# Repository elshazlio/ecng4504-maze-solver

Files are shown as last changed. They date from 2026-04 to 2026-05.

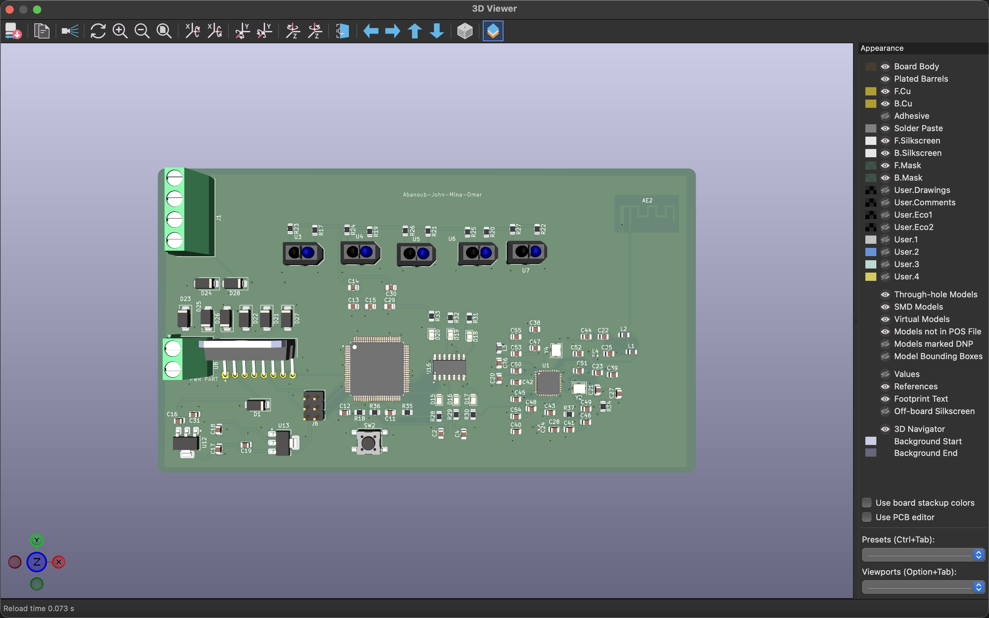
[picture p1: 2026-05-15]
Team 5 Embedded Phase 2 Submission/Screenshoots/Screenshot 2026-05-15 at 12.17.44 AM.png

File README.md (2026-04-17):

# ECNG 4504 — Autonomous maze-learning & maze-solving robot

**American University in Cairo · School of Sciences and Engineering**  
**ECNG 4504 — Embedded Systems for Wireless Communications · Spring 2026**

---

## Abstract

This project is an **autonomous line-following robot** that **learns** an unknown maze in a training pass and later **executes a shortened turn sequence** to reach the goal efficiently. A **PC host** connects over **Bluetooth** (BLE with HM-10, or **Bluetooth Classic SPP** with a ZS-040 / HC-05) to issue commands, stream status, and visualize behavior. On-robot software is a single Arduino sketch (`working_code.ino`) built around **discrete line following** (no PID), **left-hand-rule** decisions at intersections, **in-place path simplification**, and **EEPROM** persistence of the optimized path.

---

## How we approached the project

We treated the work as a loop of **measure → interpret → act → log**, repeated until the vehicle behaved reliably on real tape and real junction geometry.

1. **Hardware and sensing**  
   We brought up **five reflective sensors** (left-to-right array), **differential drive** via motor drivers, and **wireless UART on `Serial1`** (HM-10 BLE or ZS-040 / HC-05 classic) so the laptop could see the same telemetry as USB debug.

2. **Baseline motion**  
   Before worrying about mapping, we stabilized **line following** using **fixed PWM steps** and simple rules from the sensor pattern (centered forward, soft correct near center, stronger correct when the line moves under an outer sensor). This deliberately avoids PID tuning loops in favor of predictable, repeatable motion on our course.

3. **Seeing intersections**  
   Real junctions rarely match ideal drawings: wide tape, gaps, and noise meant “all black” or “wide center” could mean different things. We added **timing and lockouts** (`NODE_LOCKOUT_MS`) so the robot did not re-trigger the same junction, and **short probe moves** with **burst sampling** across the array to classify **left / straight / right** exits when possible.

4. **Training as a path string**  
   During **training**, at each real decision node the robot applies the **left-hand rule**: prefer **L**, then **S**, then **R**. The sequence of taken turns is appended to a **raw path** (`L`, `S`, `R`, or `B` for dead-end / U-turn). **Dead ends** are detected when the line is lost for long enough and recovered with a **U-turn** and a recorded **`B`**.

5. **When geometry is ambiguous**  
   For **multi-exit** junctions, recording is **deferred** briefly: after the turn, the firmware **accumulates “witness”** from the outer sensors and **scores candidate exit masks** so the stored junction record matches what the robot actually saw after committing to a turn.

6. **Optimizing the remembered path**  
   After training, the firmware **folds** the raw path: any **middle `B`** (dead-end) with neighbors is combined using **turn angles** (90° increments) so backtracking detours collapse into a single equivalent turn. That yields the **optimal path** string used in solve mode.

7. **Solve mode**  
   In **solving**, the robot walks the **optimized** sequence: at each true decision node it executes the next character of `optimalPath`. If sensor classification and the stored path disagree, it logs a **mismatch** and falls back to the left-hand choice so the run degrades safely.

8. **Host software**  
   We built a **FastAPI** dashboard with **WebSockets** (`Bluetooth stuff/maze_dashboard/`) — **Bleak** for BLE, or **pyserial** to a paired **Bluetooth SPP** serial port on macOS — plus a small **Bun** log viewer (`Bluetooth stuff/log-viewer/`) to command `TRAIN` / `START`, watch logs, and debug link issues.

**Diagrams in this repo:** high-level software structure is in [`system_architecture.png`](system_architecture.png); the PCB is exported as [`PCB Schematic.png`](PCB Schematic.png). Team and roles are in [`team.md`](team.md).

---

## Firmware: theory and implementation

The firmware implements a **maze-learning** pipeline that is **graph-free** on the MCU: the map is a **string of turns**, not an explicit adjacency list. That matches the course emphasis on embedded constraints and clear state machines.

### Line following without PID

Line tracking uses **rule-based steering** (`followLineNoPID`): the center sensor defines “on track,” left/right pairs request **differential spins** at tuned speeds (`BASE_SPEED`, `TURN_SPEED`, `ALIGN_SPEED`, etc.). There is **no PID controller**—the design trades fine continuous control for **bounded behavior** that is easier to reason about on inconsistent surfaces. After turns, **`alignToCenterStrict`** recenters on a **center-only** pattern before moving forward.

### Junction detection and training probes

A **node candidate** is inferred from reflective patterns (`nodeCandidateNow`): e.g. **all sensors on line** (wide intersection) or **outer sensors with inner body**. After a lockout window, the robot stops and runs **`inspectAndHandleNodeTraining`**: short forward motion **samples bursts** of left/right/straight visibility to set **exit masks** (bits for L, S, R). The **left-hand rule** (`selectTurn`) chooses the physical turn. **Finish** is a sustained **all-black** region confirmed as the end box (`confirmEndBox`).

### Recording and deferred resolution

For junctions with **multiple** plausible exits, the firmware may **defer** committing the recorded mask (`finalizePendingTrainingRecord`, `RECORD_RESOLVE_MS`) so post-turn sensor **witnesses** improve which mask is stored with the segment time. **Single-exit** corridors force a turn without the same ambiguity.

### Path optimization (dead-end folding)

The **raw** training path includes detours. **`buildOptimalPath`** repeatedly replaces triples where the **middle turn is `B`** by summing **turn angles** (L = 270°, S = 0°, R = 90°, B = 180°) and mapping the result back to a single letter. This removes redundant **out-and-back** structure while preserving net heading.

### Solving

**Solve** mode (`inspectAndHandleNodeSolving`) indexes **`optimalPath`** with `solveStepIndex`. Only at **true** decision nodes (multiple exits, or zero exits) does it consume the next stored turn; **forced** corridors follow the obvious exit. EEPROM (`EepromMazeData`) can persist raw and optimized paths across power cycles (`LOAD`, `CLEAR`, auto-load on boot).

### Commands and telemetry

**USB and wireless UART** share the same command set (`TRAIN`, `START`/`SOLVE`, `STATUS`, `DUMP`, `LOAD`, `CLEAR`, `STOP`). Status lines (`STATE`, `STAGE`, paths, node logs) go to both streams for the dashboard and debugging.

---

## Repository contents

| Deliverable | Location |
|---|---|
| MCU firmware (final) | [`working_code.ino`](working_code.ino) |
| Backend (FastAPI, BLE, WebSockets) | [`Bluetooth stuff/maze_dashboard/`](Bluetooth%20stuff/maze_dashboard/) |
| Web UI (log viewer) | [`Bluetooth stuff/log-viewer/`](Bluetooth%20stuff/log-viewer/) |
| BLE helper scripts | [`Bluetooth stuff/ble_log_receiver.py`](Bluetooth%20stuff/ble_log_receiver.py), [`Bluetooth stuff/ble_scan.py`](Bluetooth%20stuff/ble_scan.py), [`Bluetooth stuff/requirements.txt`](Bluetooth%20stuff/requirements.txt) |
| Bill of materials | [`component_list(1).xlsx`](component_list%281%29.xlsx) |
| Software architecture diagram | [`system_architecture.png`](system_architecture.png) |
| PCB schematic (image export) | [`PCB Schematic.png`](PCB%20Schematic.png) (also under [`KiCAD Stuff/`](KiCAD%20Stuff/)) |
| KiCAD project (native) | [`KiCAD Stuff/`](KiCAD%20Stuff/) — `Embedded Project.kicad_pro`, `.kicad_sch`, `.kicad_pcb`, `.kicad_prl` |
| Team | [`team.md`](team.md) |
| 3D / mechanical design | [`3d design/`](3d%20design/) (Fusion 360 `.f3z`) |
| Local dev (env + both servers) | [`DEV-SERVERS.md`](DEV-SERVERS.md) |

**KiCAD:** open **`KiCAD Stuff/Embedded Project.kicad_pro`** in **KiCad**. Local editor folders (`.history/`, `*-backups/`, lock files) are gitignored.

---

## Running the PC applications

The host uses the **same UART protocol** as USB; the **radio path** is either **Bluetooth Classic SPP** (ZS-040 / HC-05) or **BLE** (HM-10 / Nordic UART). Full copy-paste flows (both apps, stop commands, ports) are in **[`DEV-SERVERS.md`](DEV-SERVERS.md)**.

- **Classic SPP (`ZS-040 / HC-05`):** pair in macOS, then set `MAZE_BT_SERIAL` to the paired `/dev/cu.*` device (and `MAZE_BT_BAUD`, usually `9600`). Applies to **both** the maze dashboard and the log viewer.
- **BLE:** leave `MAZE_BT_SERIAL` unset. Point the **dashboard** at the robot with `MAZE_BLE_ADDR` (fixed address, skips scanning) or `MAZE_BLE_NAME` (scan by advertised name). The **log viewer** does **not** use `MAZE_BLE_ADDR`; it still expects `MAZE_BT_SERIAL` for Classic SPP.

**Maze dashboard (first-time venv)**

```bash
cd "Bluetooth stuff/maze_dashboard"
python3 -m venv .venv && source .venv/bin/activate && pip install -r requirements.txt
uvicorn app:app --reload --host 127.0.0.1 --port 8765
```

**ZS-040 / HC-05 on macOS (Bluetooth Classic SPP)** — pair the module in **System Settings → Bluetooth**, then pick the outgoing serial device (names vary; often under `/dev/cu.*`):

```bash
ls /dev/cu.*
export MAZE_BT_SERIAL=/dev/cu.YourModule-DevB
export MAZE_BT_BAUD=9600
cd "Bluetooth stuff/maze_dashboard"
source .venv/bin/activate
uvicorn app:app --reload --host 127.0.0.1 --port 8765
```

After a successful connection, you can use `export MAZE_BT_SERIAL=last` to reuse `bt_serial_last.json` beside `app.py`.

**Maze dashboard (BLE by address — example)**

Use when the robot is on the BLE path and you already know its address:

```bash
unset MAZE_BT_SERIAL
unset MAZE_BT_BAUD
export MAZE_BLE_ADDR=78:04:73:16:19:C7
cd "Bluetooth stuff/maze_dashboard"
source .venv/bin/activate
uvicorn app:app --reload --host 127.0.0.1 --port 8765
```

For scan-based BLE instead of a fixed address, omit `MAZE_BLE_ADDR` and optionally set `MAZE_BLE_NAME`. See `Bluetooth stuff/maze_dashboard/app.py` (module docstring) and `ble_discover.py` for UUID discovery.

**Path preview (SVG map):** The dashboard builds a **turtle-geometry** polyline from path strings and from **training/solve** turn lines in the log (`FORCED_TURN`, `SOLVE_FORCED_TURN`, `SOLVE_NODE`, etc.). The preview appends **one grid segment after the last logged turn** so the **final leg** and **forced** corridor exits show the same corners you see on the track; that step is **visualization-only** and does not change what the robot records or executes. Optional **local-only** regression tests for the map (not published on GitHub) may exist under `Bluetooth stuff/maze_dashboard/`; if you have them, run with `python -m unittest` in that folder using the project venv.

**Log viewer** (see `Bluetooth stuff/log-viewer/package.json` for scripts). This path uses `ble_log_receiver.py` and **Classic SPP only** — set `MAZE_BT_SERIAL` in the same shell.

```bash
cd "Bluetooth stuff/log-viewer"
bun install
export MAZE_BT_SERIAL=/dev/cu.YourModule-DevB
bun run serve
```

---

*Course project repository: **ecng4504-maze-solver_team_5** — maze learning and solving per the ECNG 4504 charter.*

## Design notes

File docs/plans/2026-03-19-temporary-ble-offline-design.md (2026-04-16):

# Temporary BLE Offline Mode Design

## Goal

Keep the car firmware, Bluetooth helper scripts, and local log viewer aligned with the current hardware reality while the HM-10 module is unavailable.

## Proposed Approach

Use a compile-time BLE availability flag in `working_code.ino` so the sketch keeps USB serial telemetry but does not initialize or write to `Serial1` during the outage. Keep the BLE-related code structure intact so the replacement module can be re-enabled by changing one flag instead of reconstructing earlier integration work.

Update the Bluetooth scripts and log viewer to present a clear temporary-outage state instead of trying to scan or connect to HM-10. This keeps the tooling honest and prevents wasted debugging effort on a module that is currently dead.

## Scope

- Firmware: disable HM-10 initialization and mirrored BLE telemetry
- Docs: mark the HM-10 entry and BLE workflow as temporarily unavailable
- Tools: make BLE scripts/viewer report outage status explicitly

## Non-Goals

- Permanent removal of BLE support
- Replacing Bluetooth with a different wireless transport
- Solving the current junction/phantom-turn regression in this same change

## Validation

- Host-side firmware tests still compile and pass
- BLE scripts show a temporary outage message without trying to connect
- Viewer status text reflects the offline state

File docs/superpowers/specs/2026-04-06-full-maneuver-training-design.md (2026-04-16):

# Full Maneuver Training Design

## Goal
Make training, logs, EEPROM data, and solve playback all describe the same thing: the exact maneuver stream the robot physically executed, including forced turns, decision-node turns, straight-through traversals, and dead-end U-turns.

## Problem Summary
The current firmware stores a reduced path model that intentionally records only real decision nodes and dead ends. That design no longer matches the required behavior. It also makes debugging harder because the operator sees one sequence while the firmware stores another. On top of that, the current node-selection flow can misclassify some non-left nodes as `L` because sensing and turn selection are coupled through a left-first policy.

## Recommended Architecture
Replace the current junction-only raw path model with a maneuver-stream model.

Each stored step represents one executed maneuver, not one inferred junction. A step must contain:
- maneuver turn: `L`, `S`, `R`, or `B`
- event kind: forced, decision, or dead-end
- sensed exits mask for the triggering location when applicable
- segment time for the travel leading into that step

This creates one canonical sequence that can be:
- logged directly during training
- saved to EEPROM without losing forced maneuvers
- inspected later without reconstructing hidden steps
- replayed during solve with event-aware logic

## Component Changes
### Training recorder
Training should append a step whenever the robot commits to an executed maneuver.

That includes:
- forced single-exit turns
- decision-node turns after probe resolution
- zero-exit recovery only when the firmware has positively classified a dead end
- straight-through traversals when the robot intentionally continues straight

The node probe must stop using "first available left/straight/right" as the stored-truth generator. Instead, sensing should determine what exits exist, and a separate decision step should determine which maneuver is executed and recorded.

### Data model
The current arrays store only turn char, exits mask, and segment time. They need one additional event-kind field so the firmware can distinguish:
- a forced `L` from a decision-node `L`
- a straight forced corridor continuation from a decision-node `S`
- a true dead-end `B` from a temporary zero-exit probe failure

The event kind must be persisted alongside the turn sequence in RAM and EEPROM.

### Solve playback
Solve should no longer assume that only multi-choice nodes consume stored path entries. Instead, it should replay the same maneuver stream model that training recorded.

This means solve must:
- inspect the current sensed exits
- verify the next stored maneuver is still plausible
- execute the stored maneuver with the same motor routine used in training
- surface a clear mismatch log if the maze geometry no longer matches the stored step

### Path reduction
The current optimizer reduces `xBx` patterns in a junction-only path. That logic is too weak once forced maneuvers are included.

Optimization should therefore become event-aware:
- only consider simplification across dead-end events
- never collapse across forced moves that are part of the physically required route
- preserve a raw full-stream path exactly, even if an additional derived optimized path is built later

The raw full-stream sequence is the source of truth. Any optimized sequence is secondary and must be derivable without destroying the original record.

## Data Flow
1. Training follows the line.
2. When the robot reaches a location that requires action, sensing classifies the situation.
3. The firmware decides the executed maneuver.
4. The firmware performs that maneuver.
5. The firmware records one maneuver-stream step with event kind, turn, exits, and segment time.
6. EEPROM persistence saves that full stream.
7. Solve loads the same stream and replays it step by step.

## Error Handling
- If sensing sees no exits during a normal probe, the firmware must distinguish between a confirmed dead end and a transient probe miss before recording `B`.
- If solve reaches a step whose stored maneuver is impossible for the currently sensed exits, the firmware should log a path mismatch with both the stored step and live exits.
- If EEPROM data is from the older junction-only format, the firmware should reject it or version it clearly rather than silently interpreting it as full-stream data.

## Testing Strategy
Because this change alters the storage model, behavior must be locked down with regression coverage before production edits:
- add tests for maneuver recording so forced, decision, straight, and dead-end events all append correctly
- add tests proving false-left contamination does not rewrite intended straight decisions
- add tests for EEPROM round-trip of the extended step model
- add tests for solve playback consuming forced and decision events from the same stored stream
- add tests for any optimizer so it preserves the raw stream and only reduces allowed dead-end patterns

## Success Criteria
The design is successful when:
- the training log can represent the exact physical maneuver sequence the operator observed
- the saved raw path preserves forced and decision steps without collapsing them into a junction-only abstraction
- solve playback consumes that same path model consistently
- a run that physically contains straight-through `SR` decisions can no longer be recorded as all-left unless the sensors actually reported that geometry

## Scope Boundaries
This change is focused on path semantics and recording/playback correctness. It does not require a new UI, a new communications protocol, or a large unrelated refactor of line-following motor control unless tests prove one of those layers is the root cause of a remaining misclassification.

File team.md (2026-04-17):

# Team 5: ECNG 4504

**Course:** Embedded Systems for Wireless Communications · Spring 2026  
**Institution:** American University in Cairo · School of Sciences and Engineering

## Members

| Name | ID | Email |
| --- | --- | --- |
| Abanoub Emad Said Kamel | 900201630 | [abanoubemad@aucegypt.edu](mailto:abanoubemad@aucegypt.edu) |
| John Kamal | 900212208 | [johnk.kamal@aucegypt.edu](mailto:johnk.kamal@aucegypt.edu) |
| Mina Yasser Gerges | 900214039 | [Minayasser@aucegypt.edu](mailto:Minayasser@aucegypt.edu) |
| Omar ElShazli | 900201477 | [Elshazlio@aucegypt.edu](mailto:Elshazlio@aucegypt.edu) |

---

## Contributions (aligned with this repository)

### Mina Yasser Gerges

Led the **on-robot firmware** in `working_code.ino`: maze **training** and **solving** behavior (map build, optimal path execution, left-hand-rule navigation), sensor and motion tuning, and calibration for reliable runs. Integrated **BLE (HM-10)** with the main control flow and supported **robot-side** wireless testing so the PC tools could drive and monitor the vehicle end-to-end. Also led **hardware assembly** and **reassembly** after numerous failures during bring-up, keeping the mechanical and electrical stack usable for continued software iteration.

### Abanoub Emad Said Kamel

Led **hardware**: component selection and the **bill of materials** (`component_list(1).xlsx`), wiring, and motor/sensor interfacing. Prepared the **schematic** and carried the design through **PCB layout and routing**—trace planning, **footprint placement**, **ground and power planes**, clearance and **design-rule** checks for a board that could be fabricated and assembled reliably—with the schematic exported as `**PCB Schematic.png`** in this repo.

Led **3D mechanical design in Autodesk Fusion** (**Fusion 360**): chassis and related parts, **parametric modeling**, and **assembly** so motors, sensors, and the PCB stack fit the platform; sources are in `**3d design/`** (Fusion archive per `[README.md](README.md)`).

### John Kamal & Omar ElShazli

Led **host-side software** that talks to the robot over **wireless UART** (same framing as USB), with a **dual transport** so the laptop stack could follow the hardware path from **HM-10 (BLE)** to **ZS-040 (Bluetooth Classic serial / SPP)** — often on an **HC-05**-class breakout — without rewriting the application. **Transport selection** is by environment: leave `**MAZE_BT_SERIAL` unset** for **Bleak + HM-10**, or set it to a `**/dev/cu.*`** device for **pyserial + ZS-040**.

**Maze dashboard (`Bluetooth stuff/maze_dashboard/`):**

- **FastAPI** backend with **WebSockets** so the browser gets **live telemetry** (logs, phase, paths, pause state) as the robot prints lines.
- **HM-10 path:** **Bleak** scans and connects to the advertised module, discovers **Nordic UART Service** or **HM-10-style FFE1** characteristics, and bridges notify/write to the same command and log pipeline the firmware already uses on `Serial1`.
- **ZS-040 / HC-05 path:** when the vehicle moved to a **paired Bluetooth Classic** module, the host opens a **serial port** (`pyserial`) on macOS `**/dev/cu.*`** instead of BLE — driven by `**MAZE_BT_SERIAL**` and `**MAZE_BT_BAUD**`, with optional reuse of the last good port via `**bt_serial_last.json**` so development sessions did not require rediscovering the device name every time.
- **Browser UI:** command buttons (`TRAIN`, `START`, etc.), scrollable log with tagged lines (paths, nodes, turns), and an **SVG path preview** built from firmware path strings and solve/training turn lines (turtle geometry, including visualization fixes for forced vs intersection legs).
- **Run archive** (saved sessions) and supporting helpers such as `**ble_discover.py`** to capture UUIDs and a stable BLE address for faster reconnects.

**Log viewer (`Bluetooth stuff/log-viewer/`) and streaming:**

- Bun-based **web** UI served alongside small Node/Bun glue, with `**ble_log_receiver.py`** sharing the same `**MAZE_BT_SERIAL**` / `**MAZE_BT_BAUD**` convention as the dashboard so logs could be tailed and debugged outside the full stack when needed.
- Supporting scripts `**ble_discover.py**`, `**ble_scan.py**`, and `**ble_log_receiver.py**`, plus **end-to-end testing** of dropouts, partial lines, and reconnect behavior against the real link.

**HM-10 → ZS-040 shift and challenges:**

- **Different stack on the PC:** BLE used **GATT notify/write** and scan/pair semantics; classic Bluetooth used **macOS pairing in System Settings** and **serial port enumeration**, which changed how we diagnosed “no data” (wrong `/dev/cu.*` outlet vs wrong baud vs module not connected as SPP).
- **Operational friction:** finding the correct **callout serial device**, matching **baud** to firmware (`MAZE_BT_BAUD`), and avoiding stale **BLE** assumptions when the robot no longer exposed a GATT UART service.
- **Reliability:** reconnection after sleep or unplug, **line-boundary** issues in streaming text, and keeping **one mental model** (command + log stream) across two transports so `**working_code.ino`** did not need parallel host protocols.

---

*Repository deliverables (firmware, PC apps, BOM, schematic image, mechanical CAD) are listed in `[README.md](README.md)`.*

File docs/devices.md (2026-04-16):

# Phased Implementation Plan (Arduino Mega + HM-10 + 5-Eye IR + L298N + 4 DC Motors)

## 1) Project Context and Constraints

- **MCU:** Arduino Mega 2560
- **Wireless:** HM-10 BLE 4.0 module (UART to Mega) - temporarily offline after suspected 5V overvoltage damage
- **Sensing:** 5-eye IR line sensor array
- **Actuation:** L298N motor driver + 4 yellow DC motors
- **PC side:** Python 3 already installed
- **Course constraints:** MCU code in C/C++, BLE link to PC app, autonomous training + solving behavior
- **Current temporary status:** BLE is disabled in the sketch and helper tools until the replacement HM-10 arrives; use USB serial telemetry for tuning in the meantime

---

## 2) Extra Software Prerequisites (Beyond Python 3)

## Required

1. **Arduino IDE 2.x** (or `arduino-cli`)
  - Install AVR core ("Arduino AVR Boards")
  - Needed to build/upload firmware to Arduino Mega
2. **USB-to-Serial driver** (only if your Mega clone needs it)
  - Typical chipsets: CH340 or CP210x
  - Verify serial port appears on macOS after connection
3. **Python packages**
  - `pyserial` (serial debugging and optional UART tooling)
  - `bleak` (BLE communication with HM-10 from laptop, temporarily unused until replacement hardware arrives)
  - `matplotlib` (path/maze visualization)
  - `networkx` (graph and shortest-path operations)
  - `pytest` (automated tests for planner/protocol)
4. **Git + GitHub account**
  - Required for collaboration and deliverables
5. **KiCad**
  - Required for schematics/PCB deliverables in later phase

## Recommended

1. **BLE debugging app** (LightBlue or nRF Connect)
  - Useful again after the replacement HM-10 is installed; currently blocked by the temporary BLE outage
2. **Serial monitor tool** (Arduino Serial Monitor or CoolTerm)
  - Faster telemetry debugging during motor/sensor tuning
3. **Diagram tool** (draw.io/Figma/Luidchart)
  - For architecture, FSM, and reporting diagrams

## Python package install command

```bash
python3 -m pip install pyserial bleak matplotlib networkx pytest
```

---

## 3) Firmware and PC Module Breakdown

## Firmware (Arduino Mega)

- `board_init`: pin mapping, timers, UART init, startup checks
- `motor_driver`: PWM + direction control for left/right motor groups
- `sensor_reader`: raw IR sampling and calibration normalization
- `line_controller`: line position error and steering correction logic
- `intersection_detector`: detect node/intersection events
- `maze_mapper`: store discovered nodes/edges during training run
- `path_planner`: shortest path generation from mapped graph
- `solver_executor`: execute computed path physically on track
- `ble_link`: UART protocol handling to/from HM-10 (temporarily disabled in firmware during the outage)
- `robot_fsm`: high-level states (Idle, Train, Plan, Solve, Done, Error)
- `telemetry_logger`: compact status/event output for debug and PC app

## PC (Python)

- `ble_client`: discovery/connect/read/write/reconnect logic (temporarily unavailable until replacement hardware arrives)
- `command_console`: send commands (`train`, `solve`, `stop`, `reset`)
- `status_monitor`: live stage/status/error output
- `maze_visualizer`: display mapped maze and final chosen route
- `session_logger`: save run metadata and final path per trial
- `protocol_codec`: encode/decode command and telemetry packets

---

## Known Device Addresses

| Device | Address (macOS UUID) | Notes |
|---|---|---|
| HM-10 (HMSoft) | `07B13CAC-B95B-5DB8-18DF-C4C18A5AECE1` | Temporarily offline after suspected 5V overvoltage damage; keep address for the replacement bring-up |

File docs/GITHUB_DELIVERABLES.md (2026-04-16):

# GitHub contents vs. course charter deliverables

This file ties the **[project charter](project_description.md)** (“Github repository link that has the following content…”) to **folders and files in this repository**. Use it when preparing Phase 0 / 1 / 2 zip submissions so the link matches what instructors expect.

## Phase 0 — Initial demonstration

Charter asks for a **GitHub repository link** containing:

| Deliverable | In this repo |
|---|---|
| **(a) MCU code** | Arduino sketches at repository root (e.g. `working_code.ino`, `mina_final_code.ino`, `probably_final_code.ino`). Supplementary C++ tests under `tests/` where applicable. |
| **(b) Initial software architecture and hardware schematics (KiCAD)** | `Architecture Diagram Only.docx`, `PCB Schematic.png`, `Maze.png`, `component_list(1).xlsx`, materials under `3d design/`, and any further diagrams under `docs/`. |

Also required in the **zip** (not necessarily all in Git, but often mirrored): Excel components list, demo video, contribution write-up, `team.txt`, etc.—see charter.

**Note:** Phase 0 states wireless communication is **not** required; BLE/Python tooling may still be present for team use.

## Phase 1 — Final demonstration

| Deliverable | In this repo |
|---|---|
| **(a) MCU code** | Same as Phase 0; keep the branch/tag used for the demo identifiable (commit message or release). |
| **(b) Python script code** | `Bluetooth stuff/maze_dashboard/` (main FastAPI application), plus `Bluetooth stuff/log-viewer/` if used as part of the laptop workflow. |
| **(c) Updated software architecture and hardware schematics (KiCAD)** | Updated diagrams and schematics in `docs/`, `Architecture Diagram Only.docx`, `PCB Schematic.png`, `3d design/`, etc., as revised for Phase 1. |

Document **architecture or wiring changes** in `docs/` (and/or AgDRs in `docs/agdr/`) so “any change… shall be documented along with the reason” is satisfied.

## Phase 2 — Product / PCB

| Deliverable | In this repo |
|---|---|
| **KiCAD project files, Gerbers, BOM, FSM, 3D screenshots, manufacturer screenshot** | Typically under `3d design/`, `docs/`, and any `*.kicad_*` / Gerber folders you add. Expand this section as files are committed. |

## Maintenance

When you add KiCAD projects, Gerbers, or new Python modules, update this file and the root **README** table so reviewers can find them in one pass.

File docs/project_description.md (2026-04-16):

The American University in Cairo - School of Sciences and Engineering
Department of Electronics and Communication
ECNG 4504 - Embedded Systems for Wireless Communications
Spring 2026

# ECNG 4504 Project Charter

## Project Description

This project aims to provide a hands-on experience in embedded systems through the design and implementation of an autonomous
robotic vehicle capable of learning and solving a maze with minimal user intervention. The maze consists of interconnected paths
marked on the floor, which the robot initially explores during a training phase in order to build an internal representation of the maze
structure. Based on the acquired data, the robot is then required to compute and execute the optimal path to solve the maze.
Communication between the robotic vehicle and a personal computer (PC) is established via a Bluetooth wireless link, BLE, specifically.
A Python-based application running on the PC interacts with the robot by issuing high-level commands, such as initiating the training
phase and triggering the maze-solving phase. Upon completion of the solving process, the robot transmits the final computed path back
to the PC for visualization, logging, or further analysis and it shall output some indication in real-time aws to what stage the robot is at
during solving phase.

The robotic vehicle operates autonomously while navigating the maze, ensuring accurate path detection, correct decision-making at
intersections, and reliable execution of turns without deviating from the designated track.

1. The robot’s maximum size is40 cm x 40 cm.
2. The robot’s maximum weight is2 Kg

## Robot Vehicle Constraints

The following constraints have to be met; otherwise, it will result in a deduction of 5% of the Project’s Total grade for each violation:

```
.
```
3. Using ready-made robots designed for line following isprohibited(only ready-made chassis, modules, breakout boards, etc... are
    permitted).
4. It has to be abattery-poweredSystem.
5. OnlyC/C++ programming languagesare allowed for MCU code.

## Instructions & System Constraints

Each team can consist of exactly 4 members. No more and no less. The tracks will follow these specifications:

1. The track line color is black on a white background.
2. The track line width is3 cm.
3. Only90-degreeturns are present as types of turns.
4. Track lines will contain intersections between 2 lines.

One (1) PDF representing the track for experimentation (Maze_1.pdf). The size of the printable PDF is 200cm x 200cm. Different
undisclosed tracks will be used for the evaluation in both Phase 0 and 1 of the projec.will be provided then.

During the evaluation of the project, each Team is given three (3) trials for both training and testing, and a trial is considered successful
if it completes both training and testing smoothly.
It is considered to have failed if any of these conditions occurs:

1. 360 rotations during training or testing,
2. leaving the line during training or testing,
3. manually rectified/pushed during training or testing,
4. exceeding 5 minutes during training,
5. not reaching the target point during testing
Reprogramming after/before each trial is allowed for tuning faster runs during testing. Any failed trial has to be documented with an
explanation of why it failed. However, failure to do a live-demo during dem or taking more than 3 trials will result inpenalities.

### 4.

## Phase 0 - Inital Demonstration

In this phase, you shall perform research to decide which components will be used. System architecture and coding style shall also be
agreed on. The platform (software tools, IDE, etc... ) through which all team members will work has to be unified among the members
of the same team. The robotic vehicle must successfully traverse through the maze once for training and traverse it once more for
solving it. The wireless communication is not required in this phase. A to-be-announced day will be scheduled for a live demo where
each team will be given three (3) trials.
Evaluation on this phase shall not have a great weight on the performance of the car, but rather on other aspects like
code sophistication, understanding of the code, innovative approaches, documented trials and errors, etc... ,
meaning that writing a simple, basic code that works does not guarantee getting a full mark in this phase.
Phase Deliverables - One Zip file named after Team number with the following content inside it:

1. An Excel sheet containing a list of components.
2. Pre-prepared demo video.
3. Contribution of each team member.
    Githubrepository link that has the following content:
       (a)MCU code.
(b)Initial software architecture and hardware schematics diagrams (hardware connections has to be done initially onKiCAD).

```
Phase Deadline:
```
5. Text file containing team details (names, IDs, emails, and team number).
6. Group Teammate Eval Form (online per individual)
All of the above phase delivered diagrams have to be designed properly using one of the computer-aided design (CAD) software
tools, submission of the design as just a hand-drawing is not acceptable and will be penalized for that.
23:59 Tuesday, March 10th, 2025 (week 6) - discussion and demo will be held the next day during class time.

1. Pre-prepared demo video.
2.

## Phase 1 - Final Demonstration

In this phase, you will be given a new track (i.e., you will see this track for the first time on the discussion day), on which you shall
run your robotic vehicle successfully with an added wireless communication link to the PC to implement your choice of control and
status reporting. The python script app running on your laptop/PC has to be proven to work with the robotic vehicle. Any change
in software architecture, hardware connections, etc... shall be documented along with the reason for such change. A to-be-announced
day will be scheduled for a live demo where each team will be given three (3) trials for the final track.
Evaluation on this phase shall have a larger weight on the implementation of the wireless feature and the performance of the car,
while other aspects like codesophistication, understandingofthecode,innovativeapproaches,documentedtrialsanderrors,etc...,
have less weight..

Phase Deliverables - One Zip file named after Team number with the following content inside it:

```
Contribution of each team member.
```
3. Githubrepository link that has the following content:
    (a)MCU code.
(b)Python script code.
(c)Updated software architecture and hardware schematics diagrams (hardware connections has to be done initially onKiCAD).

```
Phase Deadline:
```
4. Text file containing team details (names, IDs, emails, and team number).
5. Group Teammate Eval Form (online per individual)
All of the above phase delivered diagrams have to be designed properly using one of the computer-aided design (CAD) software
tools, submission of hand-drawing is not acceptable and will be penalized for that.

```
23:59 Friday, April 17th, 2025 (week 12) - discussion and demo will be held the next day during class time.
```
## Phase 2 - Designing the project as a product

In this phase, you are required to design the PCB using KiCAD for your car as if you were to sell it. The design has to mechanically fit in
your original car used in phase 1. all of the used components must be “in stock” on LCSC and they must adhere to PCB Manufacturi
ng&

### 1.

```
Assembly Capabilities of JLCPCB. Also, all of the components used from LCSC shall be SMD components not THT
```
. You are not allowed to choose any other manufacturer than JLCPCB, nor any other distributor than LCSC.(through hole)
One other extra requirement is a FSM diagram of your whole project, defining the behavior of your code.
Phase Deliverables - One Zip file named after Team number with the following content inside it:

```
Githubrepository link that has the following content:
(a)KiCAD project files.
```
Phase Deadline:

2. Contribution of each team member.
3. Gerber files of the PCB.
4. Screenshot from the PCB manufacturer website before ordering the PCB.
5. 3D view screenshot of your PCB in KiCAD.
6. Text file containing team details (names, IDs, emails, and team number).
7. FSM diagram of your whole project, defining the behavior of your code.
8. Group Teammate Eval Form (online per individual)
All of the above phase delivereddiagrams have to be designed properly using one of the computer-aided design (CAD) software
tools, submission of the design as hand-drawing is not acceptable and will be penalized for that.
23:59 Tuesday, May 12th, 2025 (week 15) - discussion will be held the next day during class time.

## Grading Rubric

Regarding any of the below project phases rubrics, Teams will be arranged from the best to the worst and are given the grade accordingly;
the same goes for the other aspects of the project. Also, given any rubric; every team membermust havecomplete understanding of
that item as grades are assigned individually per team members. Any violations oftheAUCCodeofAcademicEthics will be penalized
heavily.

1. Phase 0 - Inital Demonstration. (30%)
    a. Documentation and Code Organization (2%)
    b. Initial Software Architecture and Hardware Connection Diagrams (3%)
    c. A successful, smooth run on the given track (35%) - most of this grade is related to other aspects like code sophistication,
       amount of effort documented, and so on. A little weight is given to car performance (speed and smoothness).
2. Phase 1 - Final Demonstration. (40%)
    a. Wireless connectivity feature (15%)
    b. Documentation and Code Organization along with the hardware connection (5%)
    c. A successful, smooth run on the final demo day track (20%) - most of this grade is related to car performance (speed and
       smoothness), while other aspects are given lower weight.
3. Phase 2 - Designing the project as a product. (30%)
    a. hardware schematics (10%)
    b. PCB layout and design (10%)
    c. FSM diagram (5%)
d. BOM (bill of material) (2%)
e. 3D view of the PCB, screenshot from the manufacturer website along with the gerber files (3%)

## Bonus

A bonus that will not exceed 10% of the project’s total weighted grade is available. The bonus will be awarded to any of the following
contributions up to a maximum of the percentage in front of each item:

1. RTOS-based project (e.g. freeRTOS, Zephyr, etc... ) on the main car’s MCU. (10%)
2. Low-level driver implementation. (10%)
3. Applying one of the famous controllers (e.g., PID, etc... ) (10%)
4. 3D designing of the car body chassis (10%)

Any other extra work will be considered for a bonus at the discretion of the instructors and will be evaluated according to the complexity
of the work done, but the overall bonus will not exceed 10% of the project’s total weighted grade under any condition. Check with the
instructors before the phase deadline if you think you have any other item that qualifies for a bonus.

## Notes

1. The bonus gradedoesnot contributeto midterm and final exam grades. However, it can contribute to Class performance, quizzes,
    and assignment grades in case of getting a grade higher than the project total grade.
2. Completing one loop of the trackisnot sufficientto get the full grade; rather, consistent car performance on the track is taken
    into consideration upon grading with other aspects, as mentioned before.
3. You are free to choose any line tracker sensor of your choice, but due to some inconveniences your colleagues faced before, we
    recommend using thisLineTrackerSensor. Note that we have no association of any kind with any of the companies/stores linked
    in this document.
4. The delivered diagrams (FSMs, hardware connections, software architecture, etc... ) have to reflect what was actually imple-
    mented in phase 0/1; otherwise, a partial grade will be earned.
5. The “group team-mate eval” Google form is mandatory to fill out for each individual in the same team to ensure fairness in grading
    team members. This means that it is expected and quite normal that team members in the same team will get different grades. Any
    team member who doesn’t fill out the peer evaluation form by the deadline will be given 0.
6. You as a team are totally responsible for work distribution among you, meaning that, if a team member work distribution is less
    than the rest of the team, he/she would be penalized for that; so make sure to distribute the workload among you equally. In case
    you mentioned in the work distrubition sheet that “all of you worked together on the same thing”, then, during discussion, it’s
    assumed that all of you know everything about the project.

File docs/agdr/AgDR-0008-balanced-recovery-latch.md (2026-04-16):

---
id: AgDR-0008
timestamp: 2026-03-18T00:00:00Z
agent: cursor
model: GPT-5.4
trigger: user-prompt
status: executed
---

# Balanced Recovery Latch For Junction Turns

> In the context of a partially working `working_code.ino` Phase 0 maze follower, facing missed or late turns caused by staggered sensor triggering, crooked approach angles, and forward momentum through intersections, I decided to use a short guarded recovery latch that preserves recent committed junction intent only while the post-junction reading is uncertain and releases on a clearly centered follow reading, to improve turn reliability while accepting heuristic thresholds and possible hardware retuning.

## Context
- The sketch already records a committed intersection intent, but currently reuses it only during full all-black crossings.
- Real hardware can produce staggered or partial sensor patterns after a junction because the five sensors do not trigger simultaneously.
- The robot must continue respecting left-hand following, so a confidently seen left should not be discarded too quickly.
- A full follower/node/turn state machine would be more structured, but is larger and riskier than needed for this pass.

## Options Considered
| Option | Pros | Cons |
|---|---|---|
| Keep the current all-black-only latch and only retune timing constants | Smallest code change, easiest to compare with current behavior | Does not address messy partial post-junction readings, still likely to forget left too early |
| Use a balanced recovery latch during uncertain post-junction readings | Targets staggered sensors and momentum, preserves left-hand priority without overcommitting too long | Adds heuristic ambiguity rules and another timing window to tune |
| Use an aggressive sticky latch until a strong competing pattern appears | Most likely to catch late turns after overshoot | Higher risk of false turns and suppressing valid live corrections on noisy tracks |

## Decision
Chosen: **Use a balanced recovery latch during uncertain post-junction readings**, because it directly addresses the observed goldfish-memory behavior after junctions while still allowing clear live sensor patterns to retake control before the robot commits to a wrong branch.

## Consequences
- The robot should keep honoring a recent left or straight node intent through brief partial/noisy recovery readings after a junction.
- A clearly centered follow reading should release the latch so normal line following resumes promptly.
- Left-hand following remains preserved because new clear left evidence still outranks older non-left intent.
- The sketch stays heuristic; if hardware testing still shows inconsistent behavior, the next step should be a fuller state-machine rewrite rather than more ad-hoc latch growth.

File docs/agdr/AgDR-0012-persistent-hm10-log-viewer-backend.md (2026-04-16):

---
id: AgDR-0012
timestamp: 2026-03-19T00:00:00Z
agent: cursor
model: GPT-5.4
trigger: user-prompt
status: executed
---

# Use A Persistent HM-10 Viewer Backend

> In the context of the local HM-10 log viewer, facing misleading UI connection state, lost reconnect behavior after the car power cycles, and noisy unreadable sensor output, I decided to use a persistent server-managed BLE backend with UI-side grouped rendering to achieve accurate status and automatic recovery, accepting more backend state management than the current per-page spawn model.

## Context
- The current Bun page opens a WebSocket and immediately marks the UI as connected when the socket opens, even though BLE connection may still be in progress.
- The current server spawns a BLE reader per browser socket, so clearing logs or losing the BLE device often leaves the page needing a manual refresh to recover cleanly.
- The user wants sensor lines grouped between `Node detected` lines and expandable for easier reading.
- Browser-only BLE was already ruled out because the user wants automatic reconnect behavior.

## Options Considered
| Option | Pros | Cons |
|---|---|---|
| Persistent server-managed BLE session with broadcast events to the UI | Accurate BLE lifecycle state, automatic reconnect after power cycling, single source of truth for all tabs, keeps browser simple | Requires backend supervisor logic and event protocol instead of raw text piping |
| Keep per-page WebSocket and respawn BLE reader on each page load | Smaller change from current code, simpler server file | Connection state stays tied to page lifecycle, reconnects remain fragile, multiple tabs can compete for BLE |
| Return to browser-managed Web Bluetooth | Familiar direct browser API, no Python bridge | Cannot reliably auto-connect or auto-reconnect due to browser permission and gesture limits |

## Decision
Chosen: **Persistent server-managed BLE session with broadcast events to the UI**, because the core problems are lifecycle and truth-of-state problems that are best solved once in the backend instead of asking each browser tab to infer BLE status from a short-lived subprocess.

## Consequences
- The Bun server will maintain one long-lived BLE supervisor process and stream structured status/log events to the browser.
- The page will show `searching`, `connected`, and `reconnecting` based on backend events rather than WebSocket state alone.
- Sensor lines will be grouped client-side under each `Node detected` anchor for readability.
- The implementation is slightly more complex than raw stdout piping and needs tests around grouping/state behavior.

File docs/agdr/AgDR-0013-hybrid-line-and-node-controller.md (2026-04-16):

---
id: AgDR-0013
timestamp: 2026-03-19T03:59:41Z
agent: cursor
model: GPT-5.4
trigger: user-prompt
status: executed
---

# Use A Hybrid Line And Node Controller

> In the context of the maze-solving car firmware, facing phantom left turns on straight segments, missed left turns at intersections, and unreliable dead-end recovery, I decided to use a hybrid controller that separates segment following from node inspection and committed turn execution to achieve more reliable navigation, accepting a moderate firmware refactor instead of a small averaging-only tweak.

## Context
- The current `working_code.ino` mixes normal line following, intersection classification, and turn commitment in one pattern-driven path.
- The robot shows a left bias on straights, which can be amplified when outer-sensor blips are treated as immediate left turns.
- The team considered buffering the last 20 sensor readings and deciding from an average or dominant value.
- Research on similar line-maze robots consistently favored fast segment tracking plus a short stateful node-inspection phase over long averaging windows.

## Options Considered
| Option | Pros | Cons |
|---|---|---|
| Hybrid segment-following plus node FSM | Separates straight tracking from node decisions, reduces phantom-turn sensitivity, preserves left-hand-rule logic, enables explicit turn commitment and stable reacquisition | Requires refactoring `working_code.ino` and retuning multiple constants |
| Long-window averaging on current logic | Smaller code change, easy to explain, can smooth some noisy samples | Adds lag at intersections, can miss brief left branches, does not address fragile turn execution or stale latched decisions |
| Hardware-first correction with wheel encoders or tighter motor feedback | Best long-term fix for motor bias, improves straight tracking fundamentally | Larger hardware and software scope, slower to deliver, does not by itself solve brittle node classification |

## Decision
Chosen: **Hybrid segment-following plus node FSM**, because it addresses both classes of failures at the same abstraction level: continuous steering handles straight-line reliability, while explicit node inspection and committed turns handle left-hand maze decisions without relying on stale latch state or long averaging windows.

## Consequences
- `working_code.ino` will gain internal state for sensor snapshots, node scanning, turn commitment, and recovery while remaining self-contained in one file.
- Host-side regression tests will need to cover phantom-left detection, missed-left node handling, and configurable U-turn direction.
- Long averaging over 20 samples may still be used as short debounce inspiration, but not as the main control method.
- If straight drift remains after the logic redesign, a static motor trim or later hardware feedback step may still be needed.

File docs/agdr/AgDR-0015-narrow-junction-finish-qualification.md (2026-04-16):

---
id: AgDR-0015
timestamp: 2026-03-19T00:00:00Z
agent: cursor
model: GPT-5.4
trigger: user-prompt
status: executed
---

# Use Geometry-Aware Junction And Finish Qualification

> In the context of the maze-training controller in `working_code.ino`, facing missed left turns on plain 10 cm junctions and false finish detection away from the unique 20 cm finish bubble, I decided to keep the current FSM shape but make its node-release and finish-qualification logic geometry-aware to achieve more reliable traversal, accepting a moderate heuristic retune instead of a finish-only patch or a larger rewrite.

## Context
- The maze uses plain 10 cm lines with no widened junction markers.
- The finish bubble is the only 20 cm circular marker on the course.
- Current hardware runs show three linked failures: missed left turns, false finish calls at non-finish nodes, and phantom left/U-turn behavior on straights.
- The project already has a self-contained sketch and host-side regression harness that should be preserved.

## Options Considered
| Option | Pros | Cons |
|-----|---|---|
| **Retune the current FSM for narrow junctions and unique-finish geometry** | Smallest meaningful change, directly matches the real maze, preserves the current sketch/test harness | Still heuristic, needs careful regression coverage |
| **Harden finish detection only** | Lowest-risk code delta, directly addresses false stops | Leaves missed-left and phantom-turn behavior largely untouched |
| **Rewrite the controller more aggressively** | Cleaner long-term structure, more explicit state ownership | Highest change risk, slower to validate on hardware |

## Decision
Chosen: **Retune the current FSM for narrow junctions and unique-finish geometry**, because it addresses the root-cause mismatch between the controller assumptions and the real maze layout while keeping the current self-contained architecture intact.

## Consequences
- `working_code.ino` will use stricter finish qualification than a single all-black sample.
- Node-scan release and live-steering fallback will be adjusted so narrow real left branches are less likely to be dropped while stale left intent is less likely to survive into unrelated recovery patterns.
- Regression tests will be extended to cover ordinary all-black crossings, narrow left-branch commitment, and stale-latch release.

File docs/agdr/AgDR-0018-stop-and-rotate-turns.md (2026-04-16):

---
id: AgDR-0018
timestamp: 2026-03-19T18:00:00Z
agent: cursor
model: composer
trigger: user-prompt
status: executed
---

# Stop-and-Rotate for Turns and Junctions

> In the context of line-maze navigation in `working_code.ino`, facing sluggish asymmetric turns (one side stopped, one side at base speed) and unclear junction motion, I decided to use in-place spin with explicit motor stops before junction rotations and to replace soft L/R corrections with bounded spin-until-center, because that matches the requested behavior and avoids dragging a stalled wheel on low-friction surfaces, accepting slightly higher peak current draw and the need for timeout bounds to avoid overshoot loops.

## Context
- User observes slow “pivot” turns where one track runs and the other is stopped or very slow.
- Junction handling already used `spinLeft`/`spinRight` but mixed with forward motion and did not clearly separate “stop” from “rotate.”
- Left-hand rule priority at branches must remain correct.

## Options Considered
| Option | Pros | Cons |
|-----|---|---|
| **Stop motors, then in-place spin until center sensor hits line (with timeouts)** | Predictable heading change, no single-wheel drag, matches request | Higher instantaneous torque; may need tuning per surface |
| **Keep differential slow turns (one motor off)** | Smooth, continuous path | User-reported poor behavior; wheel stall/slip |
| **PID / proportional steering only** | Smooth on curves | Does not address discrete junction geometry; larger change |

## Decision
Chosen: **Stop motors, then in-place spin until center sensor hits line (with timeouts)**, because it directly fixes the reported motion and aligns with left-hand junction turns; differential L/R is replaced by the same spin-to-center pattern with a shorter timeout for small errors.

## Consequences
- `DEC_L` / `DEC_R` execute bounded `spinLeft` / `spinRight` until `SENS_PINS[2]` sees the line (or timeout).
- `DEC_SL` / `DEC_SR` / `DEC_U` use an explicit stop/settle phase before the spin phase.
- `decideDirectionFull` junction priority unchanged: left branch before straight before right.

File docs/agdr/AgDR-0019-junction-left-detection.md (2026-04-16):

---
id: AgDR-0019
timestamp: 2026-03-19T20:00:00Z
agent: cursor
model: composer
trigger: user-prompt
status: executed
---

# Broader Junction Detection for Left-Hand Rule

> In the context of 5-sensor line-maze training in `working_code.ino`, facing missed left turns because junction handling only activated when outer sensors `s0` or `s4` saw the line, I decided to treat additional geometric patterns as junctions and to resolve choices with `canLeft = s0 || s1` before straight then right, because many real T-approaches light `s1` and `s2` before `s0`, accepting that we must exclude symmetric “wide straight” `(s1,s2,s3)` without outers and keep outer-only-without-center as soft steer rather than `DEC_SL`.

## Context
- `if (leftPath || rightPath)` with `leftPath = s0` missed branches where only inner-left and center see the line.
- Left-hand rule requires the same priority once any junction is recognized: left before straight before right.

## Options Considered
| Option | Pros | Cons |
|-----|---|---|
| **Expand `atJunction` with inner patterns; `canLeft = s0 \|\| s1`; outer-only → soft L/R** | Matches hardware geometry; fixes common missed L | Needs care to avoid turning on wide straight |
| **Lower threshold / longer debounce only** | Small diff | Does not fix structural blind spot when `s0` never fires |
| **Require hardware move of leftmost sensor** | Physical reliability | User asked for firmware; extra assembly |

## Decision
Chosen: **Expand `atJunction` with inner patterns; `canLeft = s0 \|\| s1`; outer-only without center → `DEC_L` / `DEC_R`**, because the failure mode is logical (gate never opens) and inner sensors already carry left evidence at many Ts.

## Consequences
- Junction when `(s0&&s2)`, `(s4&&s2)`, `(s2&&s3&&s4)`, or **narrow left stem** `(s1&&s2&&!s3&&!s4)` **only if** `s0` is on or was seen within `LEFT_OUTER_SENSOR_MEMORY_MS` (reduces false sharp-left on tight single-line curves).
- Wide straight `(s1,s2,s3)` with no `s0`/`s4` stays in normal follow (no false `DEC_SL`).
- `s0` alone without `s1`/`s2` remains correction `DEC_L`, not a sharp junction.
- If a real left branch never passes under `s0`, increase `LEFT_OUTER_SENSOR_MEMORY_MS` or adjust sensor placement.

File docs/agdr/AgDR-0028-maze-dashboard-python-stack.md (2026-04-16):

---
id: AgDR-0028
timestamp: 2026-03-24T12:00:00Z
agent: cursor
model: claude
trigger: user-prompt
status: executed
---

# Maze control dashboard: Python stack and BLE transport

> In the context of restoring a PC-side maze robot UI with BLE, auto-refresh, and path visualization, I decided to use **FastAPI + WebSockets + asyncio Bleak** in one self-contained module under `Bluetooth stuff/maze_dashboard/`, to achieve **live duplex control and parsing aligned with `working_code.ino`**, accepting **tighter coupling to asyncio** than a threaded Flask app would need.

## Context
- Course charter (`docs/project_description.md`) requires a Python app that commands TRAIN/SOLVE, shows real-time phase status, and visualizes the returned path.
- Firmware exposes HM-10 UART at 9600 baud with lines: `STATUS:…`, `PATH_RAW:` / `PATH_OPT:` / `RESULT:`, `NODE:n:turn`, and text banners.
- Prior `ble_log_receiver.py` was stubbed offline; the dashboard must **scan, connect, reconnect**, and stream logs to the browser.

## Options Considered

| Option | Pros | Cons |
|---|---|---|
| **FastAPI + WebSocket + Bleak (async)** | One event loop for BLE and HTTP; efficient push to browser; fits Bleak’s async API | Slightly more setup than Flask; dev must use `uvicorn` |
| **Flask + threading + pyserial (USB dongle)** | Simple mental model if BLE appears as `/dev/tty.*` | Not true BLE on many setups; extra hardware; two stacks (serial vs BLE) |
| **Separate Bun server + Python BLE subprocess** | Matches older plan docs | User asked for a **Python** website; more moving parts |

## Decision
Chosen: **FastAPI + WebSocket + Bleak**, because it keeps BLE I/O and fan-out to clients on one asyncio loop, matches the firmware’s line-oriented protocol, and avoids adding a second language runtime for this deliverable.

## Consequences
- Run with: `uvicorn app:app --reload` from `maze_dashboard/` (after `pip install -r requirements.txt`).
- Browser connects via WebSocket for logs and SVG updates; commands go as JSON over the same socket.
- Tradeoff: requires `bleak` and Bluetooth permissions on the host OS; HM-10 must expose Nordic UART UUIDs (default for HM-10 firmware).

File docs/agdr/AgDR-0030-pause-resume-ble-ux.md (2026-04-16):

---
id: AgDR-0030
timestamp: 2026-03-31T12:00:00Z
agent: cursor
model: unknown
trigger: user-prompt
status: executed
---

# Pause/resume over BLE and dashboard BLE-first UX

> In the context of maze training/solving controlled from the web dashboard, facing the need to halt mid-run without losing place and to avoid queued commands before BLE links, I decided to add explicit `PAUSE`/`RESUME` commands on the robot with stage snapshotting plus UI that disables controls until BLE is connected, accepting extra firmware complexity and one more protocol surface to maintain.

## Context
- Users need to pause training or solving mid-run and continue from the same logical stage.
- Clicking Train/Solve while the backend is still scanning/connecting queued multiple commands that all executed at connect, which felt broken.
- The Phase pill stayed `UNKNOWN` because several `STAGE=` values from firmware did not map to a dashboard phase.

## Options Considered
| Option | Pros | Cons |
|---|---|---|
| **A — PAUSE/RESUME commands + paused substates** | Clear semantics; works from any controller; robot holds motors off while preserving stage snapshot | More enum values and tests in firmware |
| **B — STOP only, restart run** | Simple | Loses position/context; poor UX for long runs |
| **C — Pause only in dashboard (no firmware)** | No Arduino changes | Cannot stop motors; unsafe and ineffective |

## Decision
Chosen: **Option A**, because motors must stop on the robot and the maze state (stage string, path buffers) must remain intact until the user explicitly resumes.

## Consequences
- Firmware implements `PAUSE`/`RESUME` with snapshot of `currentStage` before showing `PAUSED_*` stages.
- Dashboard sends PAUSE/RESUME; command buttons stay disabled until `ble_connected`.
- Phase pill removed from the header; internal `phase` remains for map logic. Stage mapping extended so telemetry-derived phase updates when possible.

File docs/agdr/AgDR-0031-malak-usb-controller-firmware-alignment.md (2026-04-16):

---
id: AgDR-0031
timestamp: 2026-04-01T12:00:00Z
agent: cursor
model: GPT-5.4
trigger: user-prompt
status: executed
---

# Malak USB web controller: align with working_code.ino

> In the context of a standalone Flask + pyserial page under `Malak's Stuff/`, facing wrong baud, broken command casing, and log parsers that matched an older protocol, I decided to **standardize on USB 115200, full-word commands (TRAIN, START, STOP, …), and parsers keyed to current `logLine()` output**, to achieve **reliable control without Cursor**, accepting **Flask + threaded serial** instead of merging into the Bun BLE viewer stack.

## Context
- `Website_Embedded.py` used `cmd.lower()`, which broke STOP vs START and single-letter shortcuts that do not match `processCommand()` after `normalizeCommand()`.
- Default baud was 9600 while `working_code.ino` uses `USB_BAUD = 115200` for `Serial`.
- Status/path regexes expected strings like `Robot Started:` that the current sketch does not emit.

## Options Considered

| Option | Pros | Cons |
|---|---|---|
| **Align buttons + baud + parsers with `working_code.ino`** | Works with course firmware as-is; minimal dependencies (`flask`, `pyserial`) | UI state is heuristic (keyword scan), not a formal state machine |
| **Keep old single-letter UI and patch firmware** | Small PC change | Diverges from repo `working_code.ino` and course expectations |
| **Replace with FastAPI/Bun stack** | Matches other dashboards | Overkill for Malak’s one-file tool; user asked for “easy run” parity, not rewrite |

## Decision
Chosen: **Align the Flask app with current firmware (115200, TRAIN/START/STOP/…, log keywords like `SOLVING_DONE`, `OPTIMAL_PATH=`)**, because the bugs were protocol mismatches, not missing frameworks.

## Consequences
- Users must set `COM_PORT` / `SERIAL_PORT` to their machine’s USB serial device.
- Dashboard fields (`Running`, `Solve finished`, path) derive from telemetry keywords; edge cases may need parser tweaks if log text changes.

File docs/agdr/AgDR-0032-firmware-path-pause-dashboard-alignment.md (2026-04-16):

---
id: AgDR-0032
timestamp: 2026-04-02T12:00:00Z
agent: cursor
model: unknown
trigger: user-prompt
status: executed
---

# Firmware PATH + PAUSE/RESUME to match maze dashboard

> In the context of the Python BLE dashboard sending `PATH`, `PAUSE`, and `RESUME` while `working_code.ino` only handled a smaller command set, I decided to **extend the sketch with additive commands and four paused substates plus a resume stage snapshot**, to achieve **protocol parity without changing existing training/solving algorithms or timing constants**, accepting **more enum values and switch arms** in the main loop.

## Context
- Dashboard maps GETPATH → `PATH`, and sends PAUSE/RESUME per AgDR-0030 UX.
- Firmware must not alter maze logic, speeds, or timeouts—only new branches and reporting.

## Options Considered

| Option | Pros | Cons |
|---|---|---|
| **A — New `PATH` handler + paused `RobotState` values + `resumeStage[]` snapshot** | Matches dashboard `STATE=PAUSED_*`; RESUME restores `STAGE=` exactly; no changes to `followLine` / node logic | Larger enum and `loop()` switch |
| **B — Global `paused` flag only** | Fewer enum values | Harder to align `stateName()` with dashboard; easy to desync STATE vs motion |
| **C — Change dashboard only** | No robot flash | Does not satisfy “close mismatches” on the robot |

## Decision
Chosen: **Option A**, because it mirrors AgDR-0030 and the Python parser’s `PAUSED_*` / `STATE=` expectations while keeping all motion code paths identical when not paused.

## Consequences
- `PATH` prints path lengths and `RAW_PATH=` / `OPTIMAL_PATH=` when non-empty (subset of STATUS-style telemetry).
- Paused states hold motors off until `RESUME`; training/solving internals are unchanged.
- Tradeoff: must maintain `resumeStage` and paused enum cases when adding future motion states.

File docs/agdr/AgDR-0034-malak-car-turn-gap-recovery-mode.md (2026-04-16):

---
id: AgDR-0034
timestamp: 2026-04-02T12:15:00Z
agent: cursor
model: gpt-5.4
trigger: user-prompt
status: executed
---

# Malak car_code: turn-gap recovery mode

> In the context of `Malak's Stuff/car_code.ino`, facing the robot stopping when all three alignment sensors briefly see white while leaving a turn, I decided to remember the chosen node-exit direction and continue that recovery motion across white gaps to achieve stable turn completion, accepting a small amount of extra state and the need to tune recovery aggressiveness if the track is unusually tight.

## Context
- After a node decision, the code stays in `inIntersection` until the robot is centered on the new line.
- During that exit, `followLine()` stops the motors whenever `center`, `leftNear`, and `rightNear` are all white.
- Real turns often contain a brief white gap before the center sensor fully reacquires the new line.

## Options Considered
| Option | Pros | Cons |
|-----|---|---|
| **Coast forward on all-white while `inIntersection`** | Very simple, no extra state | Can overshoot left/right turns and ignore intended rotation direction |
| **Remember turn direction and keep recovering that way** | Matches the active maneuver, handles left/right differently, directly targets turn-gap loss | Adds state and needs a chosen recovery behavior |
| **Pure time-based grace window** | Easy to implement and tune initially | Fragile across battery level, floor friction, and different track geometries |

## Decision
Chosen: **Remember turn direction and keep recovering that way**, because the failure only happens while exiting a known maneuver and using that maneuver as context is more robust than blindly going straight or relying only on timing.

## Consequences
- A small `intersectionRecoveryMode` state is tracked across node exits.
- All-white during `inIntersection` no longer means "stop"; it means "continue the selected recovery motion."
- If recovery is too weak or too strong on hardware, the fine-turn behavior may need small tuning.

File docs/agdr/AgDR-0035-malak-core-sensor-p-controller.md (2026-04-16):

---
id: AgDR-0035
timestamp: 2026-04-02T00:20:13Z
agent: cursor
model: GPT-5.4
trigger: user-prompt
status: executed
---

# Malak line follower: core-sensor P controller

> In the context of `Malak's Stuff/car_code.ino`, facing a line follower that drifts into a slanted stance because steering is on/off and branch sensors can bias alignment, I decided to **use a proportional controller driven by the near-left, center, and near-right sensors, while keeping the far sensors for junction detection and recovery only**, to achieve **straighter line centering without weakening maze-node detection**, accepting **less aggressive recovery when only edge sensors briefly see the line**.

## Context
- `followLine()` currently applies fixed left/right steering steps, so correction strength does not scale with how far the line is from center.
- The sketch already uses the far-left and far-right sensors to detect branches and junctions.
- Letting far sensors influence normal centering can pull the robot sideways when a branch is visible.

## Options Considered

| Option | Pros | Cons |
|---|---|---|
| **Core 3-sensor P controller (`leftNear`, `center`, `rightNear`)** | Keeps the robot straighter on the main line; avoids branch-induced slant; fits existing junction logic cleanly | Recovery is softer if only an outer sensor briefly sees the line |
| **All 5 sensors in the P error** | More aggressive when the robot drifts far from center | Can bias steering toward visible side branches and reintroduce slanted tracking near nodes |

## Decision
Chosen: **Core 3-sensor proportional steering with far-sensor fallback only for reacquisition**, because the user's goal is straighter tracking on the main line, and the far sensors already have a dedicated maze-decision role.

## Consequences
- Line-follow correction becomes strength-based instead of fixed left/right steps.
- Junction detection remains based on the far sensors, so maze behavior stays consistent with the current design.
- `lineFollowKp` and `maxLineCorrection` become the main tuning knobs for centering behavior.

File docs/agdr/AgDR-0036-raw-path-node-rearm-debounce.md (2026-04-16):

---
id: AgDR-0036
timestamp: 2026-04-03T12:00:00Z
agent: cursor
model: gpt-5.2
trigger: user-prompt
status: executed
---

# Raw path duplicate junction recording (node zone re-arm)

> In the context of maze training recording, facing duplicate `RAW_PATH` characters when the robot’s sensors still report a junction after `NODE_LOCKOUT_MS`, I decided to re-arm recording only after `nodeCandidateNow()` has been false (left the junction sensor pattern), to achieve one stored decision per physical junction, accepting a small amount of extra state in the training/solving loops.

## Context
- `RAW_PATH` showed `LLLBSLBLLL` where the correct sequence was `LLBSLBLL` (extra leading and trailing `L`).
- Movement followed the left-hand rule; the bug is in when `inspectAndHandleNode*` runs, not in turn selection.
- `millis() - lastNodeHandledMs >= NODE_LOCKOUT_MS` allows a second trigger while the robot is still on the same wide/black pattern.

## Options Considered
| Option | Pros | Cons |
|---|---|---|
| **A — Increase `NODE_LOCKOUT_MS` only** | Trivial one-line change | Depends on maze geometry and speed; can still fail on long intersections or be too slow for tight mazes. |
| **B — Re-arm after `!nodeCandidateNow()`** | One decision per junction regardless of how long the pattern stays true; does not change `doTurn` / follow logic | Adds one boolean and two small branches; rare sensor flicker could still re-arm early (mitigated by keeping lockout). |

## Decision
Chosen: **B**, because it matches the physical definition of “next junction” (sensors must show a normal line segment between stored nodes) and is independent of junction size.

## Consequences
- `RAW_PATH` / `NODE n` logs should align with actual junction count.
- Solving uses the same gate so `solveStepIndex` is not advanced twice at one junction.
- Movement code paths are unchanged; only the condition that calls existing inspection functions is stricter.

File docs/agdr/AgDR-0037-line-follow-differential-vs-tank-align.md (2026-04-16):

---
id: AgDR-0037
timestamp: 2026-04-03T12:00:00Z
agent: cursor
model: composer
trigger: user-prompt
status: executed
---

# Differential forward line follow vs in-place tank correction

> In the context of maze line following in `working_code.ino`, facing unwanted in-place spinning while cruising between junctions, I decided to steer with differential forward drive during `followLineNoPID` and keep tank-style rotation only for `alignToCenterStrict` (after stops / turns) and for lost-line search, because the user wants alignment in place only when stopped after turns, accepting that gentle arcs use more runway than spot spins and tuning of soft/hard deltas may be surface-specific.

## Context
- `followLineNoPID` used `spinLeft` / `spinRight` for routine left/right error recovery, which rotates the robot in place while it should be following the segment.
- `doTurn` already calls `stopMotors()` then `alignToCenterStrict()` for post-turn centering.

## Options Considered
| Option | Pros | Cons |
|-----|---|---|
| **Differential forward (both wheels forward, asymmetric PWM)** | Matches “no tank while moving”; smooth segment tracking | Needs delta tuning; wide errors may need longer path |
| **Keep tank spins in followLineNoPID** | Strong re-centering in tight geometry | Conflicts with requested behavior; feels like constant micro-turns |
| **Reduce spin speed only** | Minimal code change | Still in-place rotation while moving; does not meet the ask |

## Decision
Chosen: **differential forward** for all non-search corrections inside `followLineNoPID`, because it separates cruise steering from explicit post-stop alignment in `alignToCenterStrict`.

## Consequences
- New `driveSteerLeft` / `driveSteerRight` helpers clamp PWM and bias left vs right while staying in forward quadrants.
- Lost-line recovery after `LOST_LINE_TIMEOUT_MS` still uses `spinLeft`/`spinRight` at `SEARCH_SPEED` to hunt for the line.

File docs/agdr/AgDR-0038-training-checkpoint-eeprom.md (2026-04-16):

---
id: AgDR-0038
timestamp: 2026-04-06T12:00:00Z
agent: cursor
model: unknown
trigger: user-prompt
status: executed
---

# Training resume after power loss via EEPROM checkpoint

> In the context of intermittent power loss during maze training, facing loss of in-RAM path state, I decided to persist partial training state in EEPROM (versioned struct with `trainingInProgress` and per-node metadata) updated after each stored node, to achieve resumable training after reboot, accepting extra EEPROM writes per junction and a one-time layout bump from v1 to v2.

## Context
- Training progress lives in `rawPath`, `exitsRecorded`, `segmentTimeMs`, and `rawPathLen`; previously only the completed run was written at `onTrainingComplete()`.
- Power loss clears RAM; PAUSE/RESUME only helps for intentional pause, not blackout.

## Options Considered
| Option | Pros | Cons |
|---|---|---|
| **EEPROM v2 extended struct + save after each `recordNode`** | Survives power loss; single storage area; matches existing `savePathsToEEPROM` pattern | More EEPROM wear (bounded by junction count); struct grows (~1kB); must not treat checkpoint as solved path for START |
| **External SD / SPI flash module** | Huge space, fewer wear concerns | New hardware, wiring, code complexity |
| **Only periodic save (e.g. every N nodes)** | Fewer writes | Can lose last N junctions on outage |

## Decision
Chosen: **EEPROM v2 extended struct with checkpoint after each recorded node**, because it matches the Mega setup, needs no new parts, and maximizes recovery fidelity for competition-style runs.

## Consequences
- `EEPROM_VERSION` becomes 2; v1 blobs are migrated on read when checksum matches legacy layout.
- `LOAD` / `START` must ignore incomplete-training blobs (`trainingInProgress`).
- New Bluetooth command `RESUME_TRAIN` arms training without clearing RAM when a checkpoint exists.

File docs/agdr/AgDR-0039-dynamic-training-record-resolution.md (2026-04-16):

---
id: AgDR-0039
timestamp: 2026-04-06T12:00:00Z
agent: cursor
model: gpt-5.2
trigger: user-prompt
status: executed
---

# Dynamic training record resolution (candidates + movement witness)

> In the context of maze training runs where junction exit sensing is noisy but driving is already tuned and must not change, facing ambiguous recorded exit topology, I decided to defer committing each training node to RAM until after the same physical maneuver completes, using burst-sampled exit hypotheses plus a short post-turn sensor witness and vote-weighted scoring to pick one stored mask, accepting extra RAM and a short delay before the path string grows.

## Context
- Recorded data (`exitsRecorded[]`, `rawPath[]`) should reflect the true junction geometry more reliably than a single probe snapshot.
- Line following, probe timings, speeds, and left-hand turn selection for **motion** must remain identical to the current sketch’s behavior.

## Options Considered
| Option | Pros | Cons |
|---|---|---|
| **A. Multi-sample burst at probe stops only** | Simple; no motion change; captures noise distribution | Does not use “movement” to disambiguate |
| **B. Deferred record + witness window + votes** | Uses post-turn observations; keeps control on first samples = old behavior | More state; record appears slightly after the turn |
| **C. Change probe distances / extra stop for resample** | Could reduce ambiguity | Violates “physical performance unchanged” |

## Decision
Chosen: **B**, because it keeps probe timing and motor commands bit-identical to the prior logic (first read in each burst matches the old single read), adds candidate hypotheses from paired burst samples, and resolves the stored mask after a bounded witness period using votes and outer-sensor hints—forced flush before the next junction so ordering stays coherent.

## Consequences
- `rawPath` / `exitsRecorded` update shortly after the turn, not atomically with `doTurn`, but before the next node is handled.
- RAM use increases slightly for candidate lists and witness flags.
- If witness is weak, resolution falls back to the primary mask from the first burst pair (same as the old single-snapshot mask).

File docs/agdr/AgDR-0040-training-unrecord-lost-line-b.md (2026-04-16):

---
id: AgDR-0040
timestamp: 2026-04-06T14:00:00Z
agent: cursor
model: gpt-5.2
trigger: user-prompt
status: executed
---

# Training: do not append raw path on lost-line dead-end recovery

> In the context of maze training where `rawPath` should reflect junction topology and probe-classified decisions, facing spurious `B` steps when the robot only lost the line briefly and ran U-turn recovery, I decided to omit `recordNode` from `handleTrainingDeadEndRecovery` while keeping motion identical, accepting that cul-de-sacs reached only via lost-line (never probed as a junction) will no longer appear in the graph.

## Context
- `persistentNoLine()` triggers the same probe + U-turn sequence as before.
- Previously every such event appended `B` with mask `DEAD`, inflating `RAW_PATH` vs operator intent.

## Options Considered
| Option | Pros | Cons |
|---|---|---|
| **A. Unrecord lost-line recovery only** | Matches goal; one code path change | Rare real dead ends seen only after line loss are not graphed |
| **B. Longer `LOST_LINE_TIMEOUT_MS`** | Fewer false triggers | Changes when recovery runs (behavior change) |
| **C. Record B only after extra confirmation** | More accurate `B` | More state, slower recovery path |

## Decision
Chosen: **A**, because the plan required unchanged physical behavior and junction logic; lost-line recovery remains the same, only the maze-memory append is skipped, with `segmentStartMs` reset like `recordNode` would.

## Consequences
- `RAW_PATH` / EEPROM training data omit U-turn recoveries that were not probe-classified dead ends.
- Logs include `DEAD_END_RECOVERY_NO_PATH` (with `segMs` for diagnostics) alongside `DEAD_END_DETECTED`.
- Probe-based `B` recording in `inspectAndHandleNodeTraining` is unchanged.

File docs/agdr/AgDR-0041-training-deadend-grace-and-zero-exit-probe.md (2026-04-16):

---
id: AgDR-0041
timestamp: 2026-04-06T18:30:00Z
agent: cursor
model: composer
trigger: user-prompt
status: executed
---

# Training: dead-end grace after junction + no raw node on zero-exit probe

> In the context of training runs where logs showed spurious `DEAD_END_RECOVERY` after forced turns and a bogus `NODE … exits=DEAD` after phantom intersections, facing misclassified `persistentNoLine` and `turnTaken == 'B'` when no probe exit was seen, I decided to gate training dead-end recovery on a short post-junction window and to stop defer-recording (and path append) when the probe reports zero exits, accepting that an all-failed probe still performs a U-turn for recovery but no longer creates a graph node, and that true dead ends are still handled by the lost-line recovery path.

## Context
- Operator trace: physical sequence used forced turns and real LSR/LS/SR nodes; firmware inserted extra `DEAD_END` and a `NODE` with `exits=DEAD` between expected steps.
- `choices == 0` implies `selectTurn` returns `'B'`, but the condition `choices >= 2 || turnTaken == 'B'` routed that into the same deferred junction path as multi-exit nodes, producing `RECORD_*` and `RAW_PATH` pollution.
- Brief no-line intervals after any `inspectAndHandleNodeTraining` exit can exceed `LOST_LINE_TIMEOUT_MS` and trigger `handleTrainingDeadEndRecovery` even when the line returns moments later.

## Options Considered
| Option | Pros | Cons |
|---|---|---|
| **A. Grace timer + fix defer condition** | Targets both failure modes; small localized change | Tuning constant needed on hardware |
| **B. Only raise `LOST_LINE_TIMEOUT_MS`** | One constant | Slows every dead-end classification; does not fix zero-exit node bug |
| **C. Retry probe when choices==0** | Might recover missed exits | Longer stop time; more code; still need a fallback |

## Decision
Chosen: **A**, because the zero-exit bug is a logic error independent of timeouts, and post-junction line loss is a known transition effect already called out in AgDR-0020-style guarding.

## Consequences
- `RAW_PATH` no longer gains a probe-only `B` when no exit was sensed; motion still calls `doTurn('B')` as a recovery attempt.
- Training dead-end recovery does not run until `DEAD_END_GRACE_AFTER_NODE_MS` after the last junction handler exit; `lastNodeHandledMs` is initialized when the train run acquires the line so the first segment is covered.

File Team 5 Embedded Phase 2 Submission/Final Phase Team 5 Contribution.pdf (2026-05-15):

# Final Phase Team 5 Contribution

Abanoub Kamel:

He acted as the Embedded Systems and Logic Designer. He focused on the core processing unit, handling the schematic design for the MCU and its essential peripherals, such as the crystal oscillator, reset circuitry, and programming headers. He also managed the integration of the Bluetooth communication module, ensuring proper signal routing for wireless data exchange. To finalize the procurement phase, he was responsible for compiling and verifying the Bill of Materials (BOM), ensuring every component’s footprint matched the physical specifications.

John Kamal:

He served as the Systems Architect and Power Electronics Lead. He was responsible for the highlevel organization of the project, including the creation of the hierarchical schematic structure and the root page that links all sub-circuits. His technical focus was the design of the power management system, where he implemented the 12V input protection and the dual-stage regulation for the 5V and 3.3V rails. Additionally, he performed the final Electrical Rules Check (ERC) to verify that the global power nets and hierarchical pins were correctly interfaced across the entire design.

Mina Yasser:

He took charge of the Sensor Array and Actuation systems. He designed the infrared sensor schematic using TCRT5000 sensors and implemented the signal conditioning logic through Schmitt triggers to ensure clean data for the MCU. He was also responsible for the motor driver stage, including the selection of the H-bridge controller and the layout of the flyback diode protection array. Beyond the hardware, he was the primary author of the Finite State Machine (FSM) diagram, defining the logical behavior and operational states of the system’s firmware.

Omar Elshazli:

He functioned as the PCB Layout and Manufacturing Engineer. His primary task was the physical realization of the circuit, which involved placing all components and routing the traces on the multi-layer board. He specifically focused on signal integrity by managing copper pours for ground planes and ensuring the Bluetooth antenna area remained clear of interference. Following the layout, he executed the Design Rules Check (DRC) to ensure the board met manufacturing tolerances and prepared the final Gerber files and 3D visualizations required for the production phase.

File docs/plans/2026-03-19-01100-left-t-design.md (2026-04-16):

# 01100 Left-T Design

## Problem

`working_code.ino` currently requires `s0`, recent `s0`, or post-left assist before `01100` can count as a narrow left stem. That means a real left T can be invisible when the robot approaches slightly right-of-center and only produces `00100 -> 01100 -> 00100`.

## Chosen Design

Keep the existing strict handling for stale/free-floating `01100`, but add one extra context gate: if the previous sampled pattern was a clean centered `00100`, then a current `01100` should count as a left junction and return `DEC_SL`.

## Why This Design

- It fixes the exact confirmed blind spot without making every isolated `01100` a left turn.
- It is a self-contained single-file change in `working_code.ino`.
- It preserves the existing post-left assist and `s0Recently` logic rather than replacing it.

## Expected Behavior

- `00100 -> 01100` should commit `DEC_SL` even if `s0` never fired.
- Stale `01100` reached from some other prior pattern should still return `DEC_S` unless existing `s0` or assist gates apply.
- Existing left-junction and close-successive-left behavior should remain intact.

## Testing

- Add a regression test that proves `00100 -> 01100` now commits left.
- Keep the stale-`01100` test to prove the broader strictness remains.
- Run the targeted host-side regression binaries after the code change.

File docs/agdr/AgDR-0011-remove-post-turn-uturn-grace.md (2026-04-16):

---
id: AgDR-0011
timestamp: 2026-03-18T00:00:00Z
agent: cursor
model: GPT-5.4
trigger: user-prompt
status: executed
---

# Remove Post-Turn U-Turn Grace

> In the context of the current `working_code.ino` Phase 0 maze follower, facing a robot that now handles many junctions better but fails to recover when it misses a short dead-end branch, I decided to remove the global post-turn grace window that blocks dead-end U-turn classification and return to pure dead-end confirmation timing to restore prompt recovery, accepting some risk that the earlier false post-turn U-turn symptom could reappear.

## Context
- `AgDR-0010` added a global post-turn grace window to suppress false `DEC_U` decisions shortly after completed tank turns.
- Hardware testing now shows a different failure mode: after missing a short left dead-end, the robot continues straight into line loss and does not recover promptly.
- The reference sketch does not include a post-turn grace window and reportedly does not miss recovery at this dead end.
- A fuller turn/follow state machine would separate post-turn settle logic from genuine dead-end handling more cleanly, but that is larger than needed for this pass.

## Options Considered
| Option | Pros | Cons |
|---|---|---|
| Remove the global post-turn grace and rely on `DEAD_END_CONFIRM_MS` alone | Smallest code change, restores prompt dead-end recovery, matches the simpler reference behavior more closely | May reintroduce some false post-turn `DEC_U` calls on noisy exits |
| Keep the grace window and only broaden left-branch detection | Preserves the recent false-U-turn protection | Does not address the reported failure where the robot already missed the branch and then cannot recover cleanly |
| Replace the grace heuristic with a fuller movement state machine | Most structured long-term solution | Much larger change and higher regression risk for the current sketch |

## Decision
Chosen: **Remove the global post-turn grace and rely on `DEAD_END_CONFIRM_MS` alone**, because the currently observed hardware failure is not just a missed branch but a failure to recover once the line is lost, and restoring immediate confirmed dead-end handling is the smallest change that directly targets that regression.

## Consequences
- Genuine dead ends should trigger `DEC_U` again as soon as sustained no-line loss passes `DEAD_END_CONFIRM_MS`.
- Missed short dead-end branches should be less likely to devolve into a long blind drive and uncontrolled spin.
- The earlier false-U-turn symptom after sharp turns may need to be re-tested on hardware and could require a more specific future fix if it returns.

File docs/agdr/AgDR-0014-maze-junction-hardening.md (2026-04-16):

---
id: AgDR-0014
timestamp: 2026-03-19T00:00:00Z
agent: cursor
model: GPT-5.4
trigger: user-prompt
status: executed
---

# Use Targeted Maze Junction Hardening

> In the context of the maze-training controller in `working_code.ino`, facing missed left turns at junctions and false finish detection near all-black overlaps, I decided to use targeted maze junction hardening to achieve more reliable traversal without destabilizing the rest of the controller, accepting a moderate logic change instead of a tiny tuning pass or a larger control rewrite.

## Context
- The current controller already performs left-hand following reasonably well on much of the maze.
- The run log shows two concrete failures: a left branch is detected but missed, and a later all-black condition is treated as finish even though the car is not at the real terminal marker.
- The project needs a reliability-focused improvement quickly, without replacing the whole controller architecture.

## Options Considered
| Option | Pros | Cons |
|-----|---|---|
| **Targeted hardening of follow, node-scan, and finish logic** | Directly addresses the observed failures, preserves the current controller shape, fits the existing host-side test harness | Requires touching several interacting heuristics and retuning them together |
| **Tuning only** | Fastest change, smallest code delta, easy to trial on hardware | Likely to leave the false-finish bug intact, may only mask the missed-left symptom |
| **Larger controller rewrite** | Strongest long-term structure, cleaner state handling, more room for future improvements | Highest regression risk, longer implementation time, too disruptive for the current need |

## Decision
Chosen: **Targeted hardening of follow, node-scan, and finish logic**, because it fixes both observed failures at the correct layer of behavior while keeping the existing self-contained sketch and test harness intact.

## Consequences
- `working_code.ino` will gain stricter finish qualification, softer normal-follow corrections, and safer node-scan commitment rules.
- The host-side regression tests will expand to cover the exact missed-left and false-finish patterns seen in the run log.
- The controller may become slightly slower or more conservative at junction entry in exchange for higher reliability.

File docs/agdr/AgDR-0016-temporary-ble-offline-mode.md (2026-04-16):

---
id: AgDR-0016
timestamp: 2026-03-19T00:00:00Z
agent: cursor
model: GPT-5.4
trigger: user-prompt
status: executed
---

# Use A Temporary BLE Offline Mode

> In the context of the maze car firmware and support tooling, facing a burned-out HM-10 module and a temporary loss of Bluetooth hardware, I decided to use a compile-time BLE offline mode to achieve safe firmware behavior and accurate tooling/docs during the outage, accepting a small restoration step later instead of hard-removing BLE support or leaving stale HM-10 behavior in place.

## Context
- The current HM-10 module is unavailable after suspected 5V overvoltage damage.
- `working_code.ino` still initializes `Serial1` and mirrors telemetry to the BLE path.
- The repository also contains BLE scripts and a local log viewer that currently assume HM-10 availability.
- The outage is temporary; the codebase should remain easy to restore once replacement hardware arrives.

## Options Considered
| Option | Pros | Cons |
|-----|---|---|
| **Compile-time BLE offline mode** | Safe temporary behavior, preserves USB serial telemetry, easy to reverse later, keeps BLE structure documented | Requires touching firmware plus support tools |
| **Hard-remove BLE code and tooling for now** | Smallest runtime surface, simplest immediate code | Loses restoration path clarity and risks rework later |
| **Docs-only update** | Fastest documentation pass | Leaves the sketch and tools behaving as if BLE still exists |

## Decision
Chosen: **Compile-time BLE offline mode**, because it reflects the real hardware outage accurately while preserving a clean path to re-enable HM-10 support later.

## Consequences
- `working_code.ino` will stop initializing or writing to `Serial1` while the outage flag is off.
- USB serial remains the active telemetry path for tuning and debugging.
- BLE helper scripts and the local viewer will report the temporary outage instead of attempting real connections.

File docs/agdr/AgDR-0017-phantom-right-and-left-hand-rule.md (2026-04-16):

---
id: AgDR-0017
timestamp: 2026-03-19T12:00:00Z
agent: cursor
model: composer
trigger: user-prompt
status: executed
---

# Stricter Junction Detection and Left-Hand Rule Enforcement

> In the context of maze navigation in `working_code.ino`, facing phantom right turns, poor straight-line centering, and incorrect left-hand rule behavior at junctions, I decided to tighten junction detection and remove early right commits to achieve reliable left-hand rule following and fewer false turns, accepting that right-only junctions are now handled via curve-following rather than discrete node scan.

## Context
- Robot takes phantom right turns on curves and straights.
- Robot does not center itself well on straight paths.
- Robot detects hard lefts but sometimes turns right anyway.
- Robot gets lost in white space after wrong turns and spins until it finds the line.
- Left-hand rule is not followed correctly at junctions.

## Options Considered
| Option | Pros | Cons |
|-----|---|---|
| **Stricter junction triggers + remove early right commit** | Eliminates phantom rights from curves, enforces left-hand rule, improves centering | Right-only junctions no longer start node scan; robot follows curve instead of recording discrete R |
| **Add temporal debounce only** | Smaller change, might reduce glitches | Does not fix root cause: right+center triggers junction on curves |
| **Require 4+ sensors for junction** | Strong filter | May miss real junctions, too aggressive |

## Decision
Chosen: **Stricter junction triggers + remove early right commit**, because rightEdgeSeen+centerSeen alone is indistinguishable from a curve and was the primary cause of phantom rights. Requiring wideCenterSeen+edge or leftEdgeSeen+centerSeen ensures we only start node scan at real junctions.

## Consequences
- `shouldStartNodeScan`: no longer triggers on rightEdgeSeen+centerSeen alone; wideCenterSeen alone (centered-on-straight) no longer triggers.
- `initialNodeDecision`: wideCenterSeen with edge returns left if left seen, else straight.
- Removed early return in `handleNodeScan` when right+center seen without foundLeft.
- `chooseNodeDecisionFromEvidence`: right requires 3+ evidence and !foundLeft.
- `FOLLOW_SOFT_THRESHOLD` lowered from 700 to 500 for better centering.
- Right-only junctions: robot follows the curve via chooseFollowDecision; no discrete R recorded in path.

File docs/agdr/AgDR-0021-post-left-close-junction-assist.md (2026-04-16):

---
id: AgDR-0021
timestamp: 2026-03-19T20:19:12Z
agent: cursor
model: GPT-5.4
trigger: user-prompt
status: executed
---

# Post-Left Close Junction Assist

> In the context of `working_code.ino` maze navigation, facing a repeatable miss where the robot completes one left turn and then drives straight through the next very short-distance preferred-left junction, I decided to add a short post-left close-junction assist window so inner-left plus center evidence can still commit left immediately after a left turn, to achieve reliable left-hand-rule behavior on closely spaced nodes, accepting a small amount of extra post-turn state and bounded risk of post-left overcommit.

## Context
- Hardware now behaves consistently and correctly on most of the maze, isolating one remaining repeatable failure.
- The missed branch occurs specifically after a successful left turn when the next left-preferred junction arrives very quickly.
- Current `narrowLeftStem` logic requires `s0` or recent `s0` evidence before treating `s1+s2` as a committed left junction.
- On a very short post-left segment, the next branch can plausibly appear as `01100` before `s0` ever lights.

## Options Considered
| Option | Pros | Cons |
|-----|---|---|
| **Short post-left close-junction assist window** | Targets the exact geometry; preserves current stricter global left detection; smallest logic change that matches the observed failure | Adds more post-turn state and timing to tune |
| Always treat `01100` as a left junction | Very simple; fixes any branch that never reaches `s0` | Higher risk of phantom lefts on tight curves or noisy left-leaning tracking |
| Motion-only retune (`JUNCTION_CREEP_MS`, speed, settle) | No new decision-state logic | Does not fix the logical blind spot when `01100` is explicitly rejected |

## Decision
Chosen: **Short post-left close-junction assist window**, because the failure is context-specific and the most robust fix is to preserve strict global junction rules while selectively allowing immediate post-left `01100` evidence to commit the next left.

## Consequences
- Closely spaced left-after-left nodes can commit even if `s0` is not seen first.
- Global false-left resistance on ordinary curves remains stricter than with a blanket `01100 => DEC_SL` rule.
- The added assist window must expire or clear on stable straight reacquisition so it does not leak into unrelated segments.

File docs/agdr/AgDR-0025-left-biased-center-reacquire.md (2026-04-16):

---
id: AgDR-0025
timestamp: 2026-03-19T21:28:00Z
agent: cursor
model: GPT-5.4
trigger: user-prompt
status: executed
---

# Left-Biased Center Reacquire

> In the context of `working_code.ino` committed-left execution, facing a regression where ordinary left junctions were missed after the new non-blocking turn FSM because the turn stayed active until a strict `00100` lock appeared, I decided to treat a left-biased center reacquire as valid committed-left completion to achieve pre-refactor left-junction timing on tight exits, accepting a bounded risk of ending the turn slightly earlier on some left-heavy samples.

## Context
- `AgDR-0022` replaced the blocking left-turn execution with a non-blocking committed-left state machine.
- The previous blocking align path stopped as soon as the center sensor saw line, even if the pattern was left-biased like `01100`.
- The new FSM only completes on two consecutive strict center-only samples, so `01100` can keep the robot spinning through a real outgoing left junction until timeout.
- `AgDR-0023` post-left assist cannot help if the committed-left maneuver never completes in time to arm it.

## Options Considered
| Option | Pros | Cons |
|-----|---|---|
| **Accept left-biased center reacquire for committed-left completion** | Closest behavioral match to the pre-FSM turn exit; directly addresses the observed missed-left regression; small self-contained change | Can complete a little earlier than strict `00100`; requires careful regression coverage |
| Keep strict `00100` completion and increase timeouts/assist windows | Minimal structural change; preserves strict lock definition | Does not address the actual blind spot while `01100` is present; likely maze-specific retuning |
| Rework the committed-left FSM into a larger inspection/exit model | Most explicit long-term model of junction exit state | Higher risk and larger scope than needed for the current regression |

## Decision
Chosen: **Accept left-biased center reacquire for committed-left completion**, because the regression comes from over-constraining turn completion relative to the earlier behavior, and relaxing completion to allow `01100` is the smallest fix that restores timely post-left decision-making.

## Consequences
- `serviceCommittedTurn()` completion will allow a center lock with inner-left support, not only pure center-only.
- Regression tests must prove that `01100` during committed-left spin can complete the maneuver and expose the next close left.
- Future tuning may still revisit the full exit-state model if hardware data shows this relaxed reacquire is too permissive.

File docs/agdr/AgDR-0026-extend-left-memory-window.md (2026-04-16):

---
id: AgDR-0026
timestamp: 2026-03-19T21:35:26Z
agent: cursor
model: gpt-5.3-codex-high
trigger: user-prompt
status: executed
---

# Extend Left Outer Sensor Memory Window

> In the context of `working_code.ino` junction classification, facing continued missed left turns where `01100` appears after `s0` drops, I decided to extend `LEFT_OUTER_SENSOR_MEMORY_MS` to preserve recent outer-left evidence longer and keep the narrow-left branch gate open, to achieve better left-junction capture without globally forcing `01100 => DEC_SL`, accepting some extra risk of left over-commit on tight left-leaning curves.

## Context
- Current logic only treats `01100` as a left junction when `s0` is live, recent, or a post-left assist is active.
- Hardware still reports missed lefts, indicating the existing `LEFT_OUTER_SENSOR_MEMORY_MS` (120 ms) can expire before `01100` is sampled.
- The user selected a balanced strategy over a global always-left `01100` rule.

## Options Considered
| Option | Pros | Cons |
|-----|---|---|
| **Always classify `01100` as `DEC_SL`** | Maximizes left capture when `s0` never fires | Higher phantom-left risk on tight curves/noise |
| **Increase `LEFT_OUTER_SENSOR_MEMORY_MS`** | Preserves existing guardrails while widening valid junction timing; minimal code change | Still depends on seeing `s0` at least briefly; needs tuning |
| **Telemetry only (no behavior change)** | Data-driven tuning with less immediate behavior risk | Does not resolve current missed-left behavior now |

## Decision
Chosen: **Increase `LEFT_OUTER_SENSOR_MEMORY_MS`**, because it directly targets the observed timing miss while keeping the stricter junction model that avoids broad `01100` over-classification.

## Consequences
- `01100` can still commit left for a longer window after a real `s0` glimpse.
- Existing protections against broad false-left commits remain in place.
- If misses continue, next step is either larger window tuning or temporary telemetry capture to measure real sensor timing.

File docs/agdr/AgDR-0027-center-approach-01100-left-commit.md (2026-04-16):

---
id: AgDR-0027
timestamp: 2026-03-19T22:00:16Z
agent: cursor
model: GPT-5.4
trigger: user-prompt
status: executed
---

# Use Centered Approach As 01100 Evidence

> In the context of `working_code.ino` left-junction classification, facing missed left Ts where the real sensor sequence can be `00100 -> 01100 -> 00100` and `s0` never fires, I decided to treat `01100` as a committed left junction when it immediately follows a clean centered approach sample, to achieve left-T visibility without globally forcing every isolated `01100` to turn left, accepting some residual risk of false left commits on certain center-to-left curve transitions.

## Context
- Current `narrowLeftStem` logic only accepts `01100` when `s0` is live, recently seen, or the post-left assist window is active.
- That creates a real classifier blind spot when hardware stays slightly right-of-center and never lights `s0` at a true left T.
- A blanket `01100 => DEC_SL` rule would fix the blind spot but would also reopen the broader "tight left curve looks like a junction" problem that earlier hardening changes were trying to avoid.

## Options Considered
| Option | Pros | Cons |
|-----|---|---|
| **Always classify `01100` as `DEC_SL`** | Fully removes the `s0` blind spot; very small code change | Highest false-left risk on tight curves and noisy left-leaning tracking |
| **Classify `01100` as `DEC_SL` only after an immediate centered `00100` approach** | Fixes the reported `00100 -> 01100 -> 00100` blind spot; keeps stale/free-floating `01100` stricter than blanket always-left | Still heuristic; can still over-commit if a curve presents the same transition |
| **Keep the existing `s0`/assist-only gate** | Lowest false-left risk; no new state | Leaves the reported junction literally unobservable when `s0` never fires |

## Decision
Chosen: **Classify `01100` as `DEC_SL` only after an immediate centered `00100` approach**, because it directly addresses the confirmed blind spot while preserving a meaningful context gate around `01100` instead of making every isolated `01100` a left turn.

## Consequences
- True left Ts can now commit left even when `s0` never appears.
- Existing tests that only prove stale, ungated `01100` should stay straight can remain meaningful if they do not include a centered approach immediately before the sample.
- Regression coverage must prove both sides: `00100 -> 01100` commits left, while stale standalone `01100` still stays straight.

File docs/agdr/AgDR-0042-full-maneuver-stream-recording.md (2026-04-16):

---
id: AgDR-0042
timestamp: 2026-04-06T19:00:00Z
agent: cursor
model: gpt-5.4
trigger: user-prompt
status: executed
---

# Training and solve: record the full maneuver stream

> In the context of maze training where the car physically executes forced turns, real decision nodes, and dead-end U-turns, facing logs and EEPROM paths that only stored a reduced junction-only sequence and also misclassified some straight decisions as left turns, I decided to store and replay the full maneuver stream with explicit event typing to achieve one consistent source of truth across motion, logs, persistence, and solve playback, accepting a broader refactor of the training, optimization, and solve pipeline.

## Context
- The operator expects the learned path to match the car's real maneuver sequence, including forced left, forced right, straight-through, node decisions, and dead-end U-turns.
- The current firmware explicitly treats `rawPath` as "real junction decisions only", so forced turns are omitted by design.
- The current training probe also selects turns with left-hand priority, which can lock a node into `L` when left is spuriously seen and can suppress intended `S` decisions from the stored path.
- A path model that omits physically executed maneuvers makes logs, EEPROM data, and solve behavior diverge from what the robot actually did.

## Options Considered
| Option | Pros | Cons |
|---|---|---|
| **A. Patch the current junction-only recorder** | Smallest code change; least disruption to EEPROM and solver shape | Preserves the wrong abstraction for the requested behavior; forced maneuvers still have to live outside the stored path; debugging remains ambiguous |
| **B. Store the full maneuver stream with explicit event types** | Matches physical behavior exactly; gives logs, storage, and solving one shared model; makes forced vs decision events explicit; easier to debug and verify | Requires coordinated changes across training, persistence, optimization, and solve playback |
| **C. Keep junction-only storage and add richer logs beside it** | Improves observability with lower risk than a full model change | Still leaves two incompatible truths in the firmware and does not satisfy the requirement that the learned path record everything |

## Decision
Chosen: **B**, because the requirement is to learn what the car actually did, not a reduced abstraction of selected junctions, and a single full-stream model is more reliable than trying to keep a junction-only path and side-channel maneuver logs in sync.

## Consequences
- Training will append every executed maneuver to the raw learned sequence and will tag each step with its event kind.
- The code will stop depending on left-hand-priority selection as both the decision policy and the stored-path abstraction.
- Solve playback will be updated to consume the same maneuver stream model rather than assuming only decision nodes are persisted.
- Path reduction logic will need stricter rules so dead-end simplification does not collapse unrelated forced maneuvers.

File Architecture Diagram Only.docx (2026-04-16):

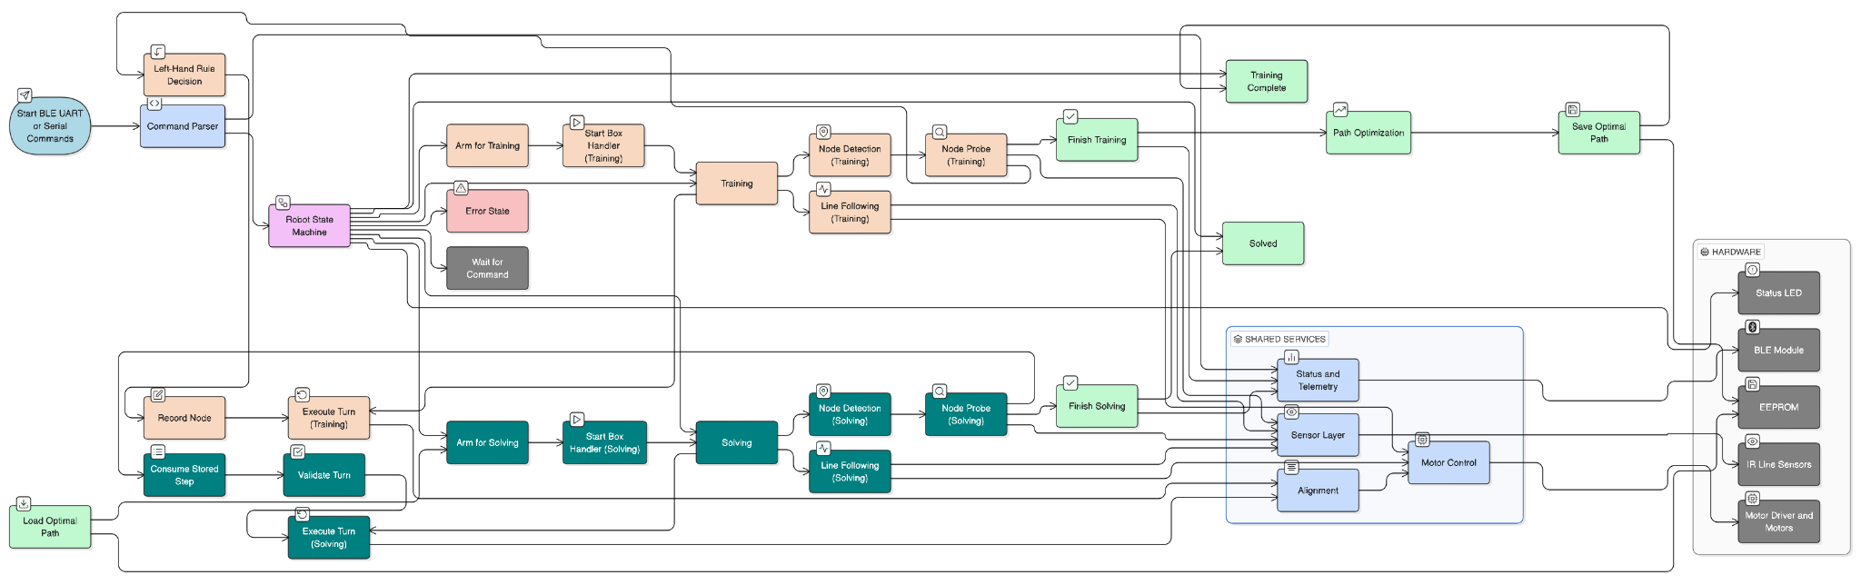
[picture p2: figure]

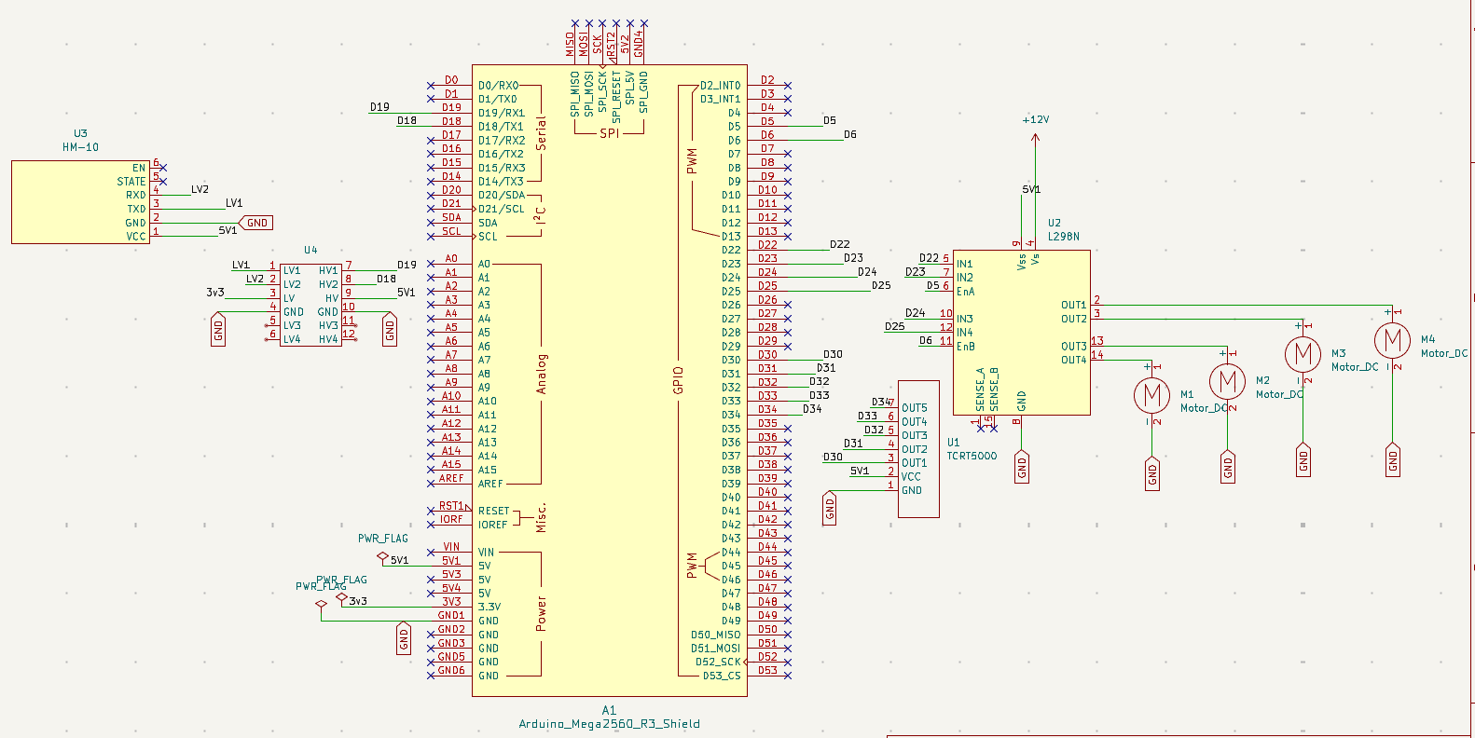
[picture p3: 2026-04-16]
KiCAD Stuff/PCB Schematic.png

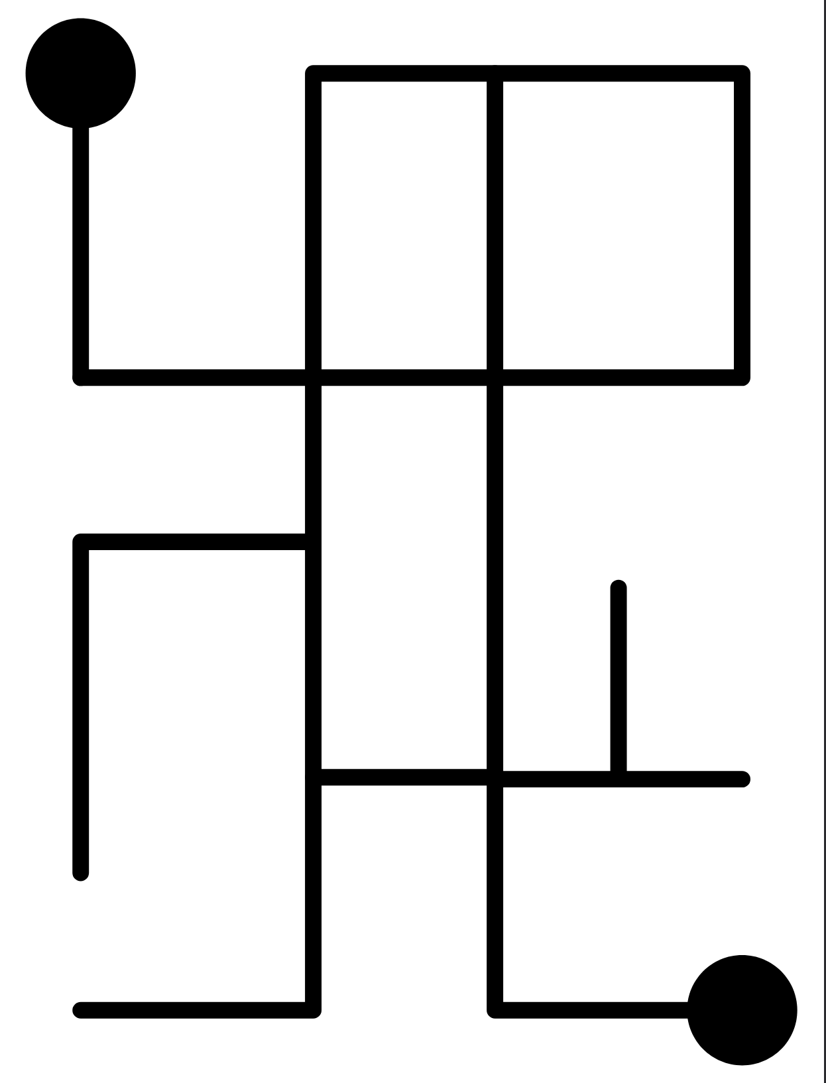
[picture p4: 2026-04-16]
Maze.png

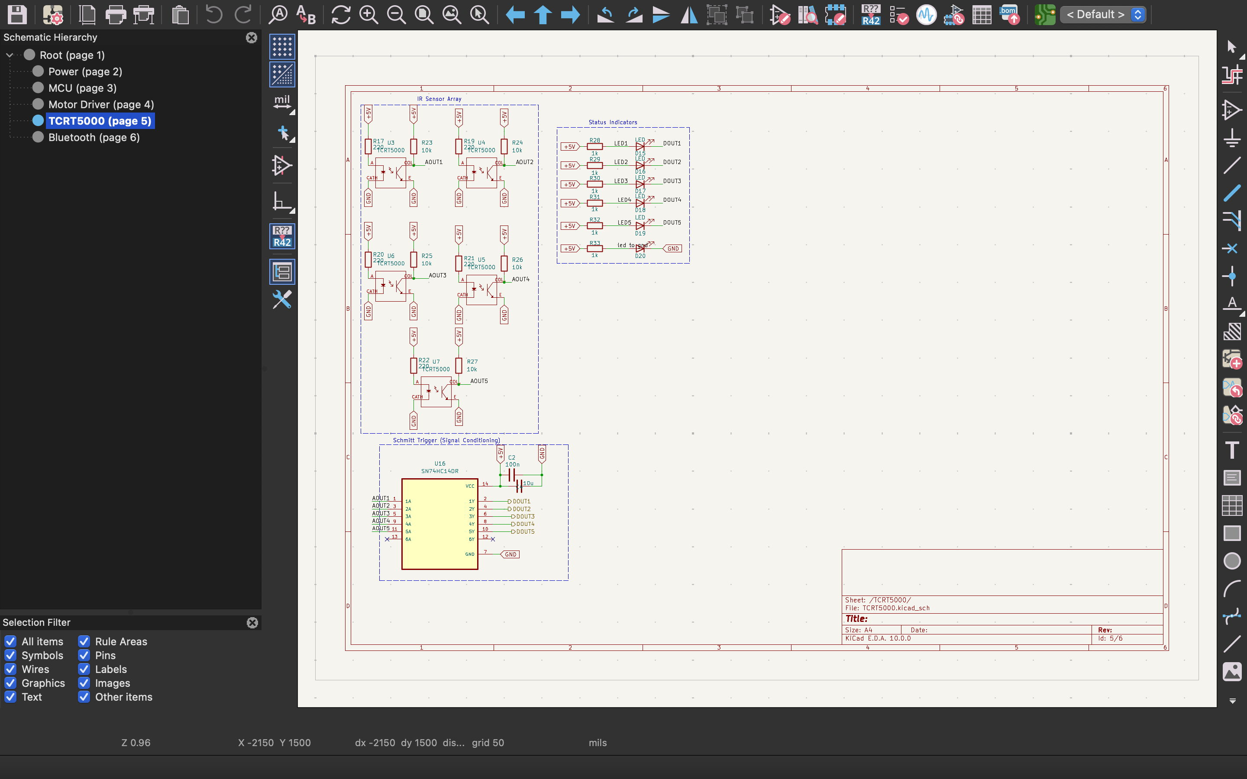
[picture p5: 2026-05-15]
Team 5 Embedded Phase 2 Submission/Screenshoots/Screenshot 2026-05-14 at 8.07.58 PM.png

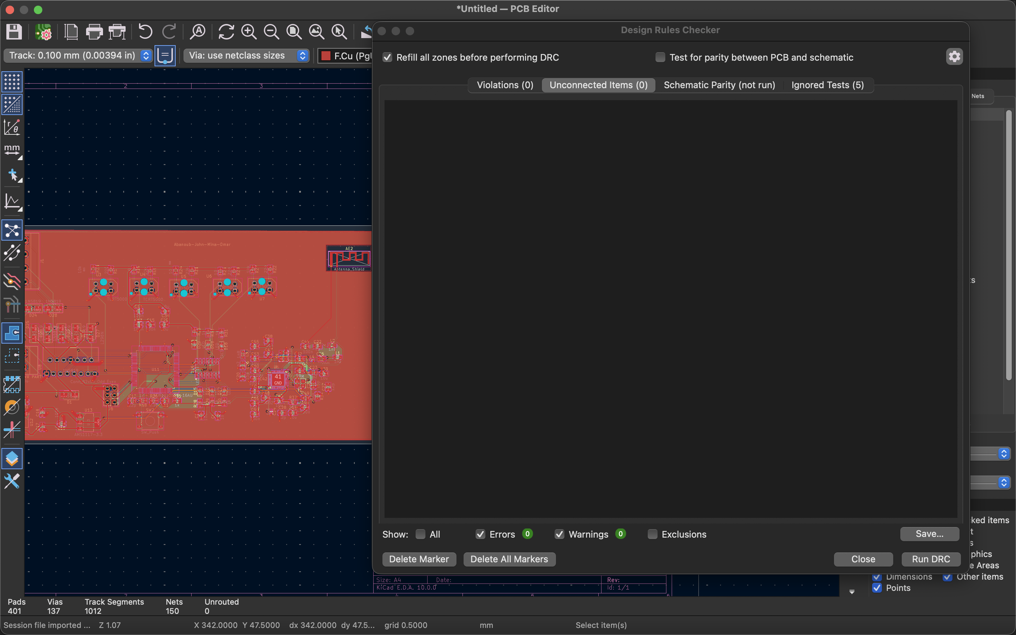
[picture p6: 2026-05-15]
Team 5 Embedded Phase 2 Submission/Screenshoots/Screenshot 2026-05-15 at 12.17.27 AM.png

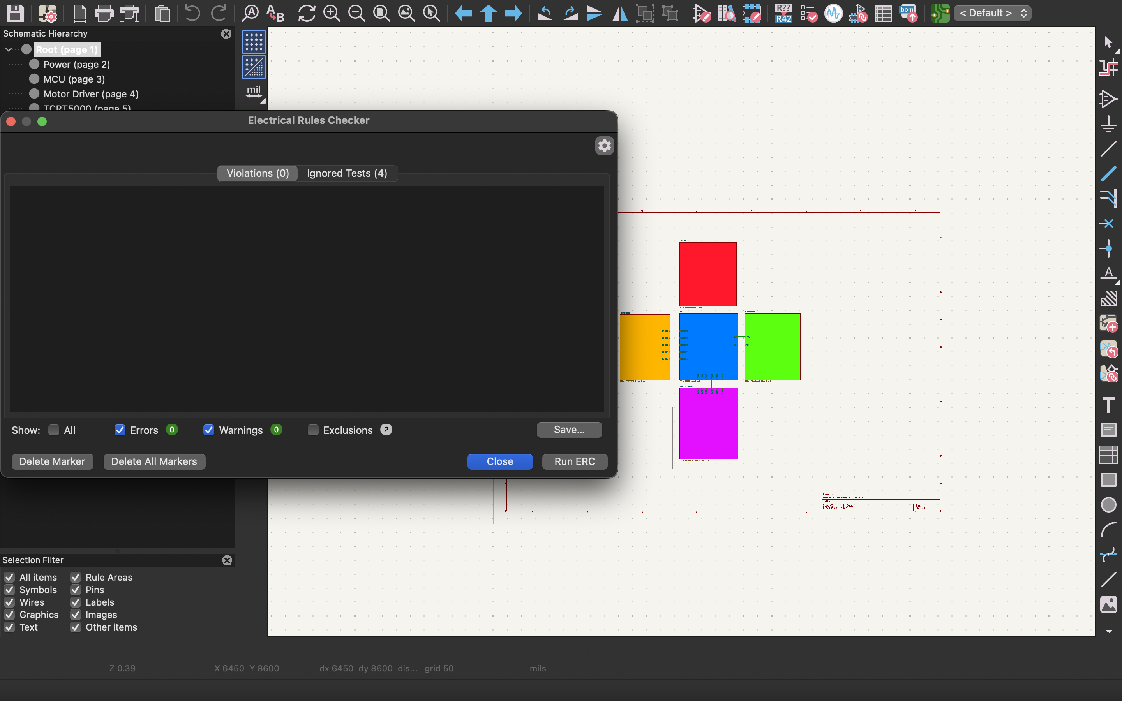
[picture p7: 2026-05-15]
Team 5 Embedded Phase 2 Submission/Screenshoots/Screenshot 2026-05-14 at 8.20.25 PM.png

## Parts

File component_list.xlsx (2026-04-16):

Bill of Materials: Maze-Solving Robot
ECNG 4504: Embedded Systems for Wireless Communications | Spring 2026 | The American University in Cairo
Team Members: Mina Gerges, Omar ElShazli, Abanoub Emad, John Fahmy
# | Component | Description / Specification | Category | Qty | Unit Cost | Notes
1 | Arduino Mega 2560 | ATmega2560 MCU, 54 digital I/O, 16 analog inputs, 4 UARTs, USB-B | MCU | 1 | ~1,300 EGP | Main controller; clone board with CH340 USB-serial
2 | L298N Dual H-Bridge Motor Driver | 2-channel DC motor driver, 5–35 V, 2 A per channel, onboard 5 V regulator | Actuation | 1 | ~75 EGP | Drives left and right motor pairs
3 | HM-10 BLE 4.0 Module | CC2541 BLE UART transceiver, 3.3 V logic, 9600 baud default | Communication | 1 | ~340 EGP | Connected to Mega Serial1 (TX1/RX1, pins 18/19)
4 | 5-Channel IR Line Sensor Array | 5-eye reflective IR sensor, digital output (active LOW), 3.3–5 V | Sensing | 1 | ~145 EGP | Pins 30–34; detects black line on white surface
5 | TT Gearmotor (DC 3–6 V) | Dual-shaft plastic gearmotor, ~200 RPM at 5 V, 1:48 gear ratio | Actuation | 4 | ~40 EGP | Yellow hobby motors; paired L+R via L298N
6 | 65 mm Rubber Wheel | Press-fit wheel for TT gearmotor D-shaft | Mechanical | 4 | ~35 EGP | Black rubber tire, yellow hub
7 | 4WD Acrylic / MDF Robot Chassis | Two-layer laser-cut chassis kit with standoffs and mounting holes | Mechanical | 1 | ~370 EGP | Holds all components; ~25 × 15 cm footprint
8 | Half-Size Breadboard (400 tie-points) | Solderless breadboard for prototyping sensor and BLE wiring | Prototyping | 1 | ~95 EGP | Mounted on chassis upper deck
9 | Male-to-Male Jumper Wires | Assorted 10–20 cm dupont jumper wires | Prototyping | 1 | ~35 EGP | Bundle; sensor, motor driver, and BLE connections
10 | Male-to-Female Jumper Wires | Assorted 10–20 cm dupont jumper wires | Prototyping | 1 | ~35 EGP | Bundle; Arduino header to breadboard
11 | 18650 Li-Ion Battery | 3.7 V rechargeable lithium-ion cells, ~2600 mAh | Power | 2 | ~135 EGP | Series pair → 7.4 V nominal to L298N VMS
12 | 18650 Battery Holder (2-cell series) | Plastic holder with leads, series wiring | Power | 1 | ~15 EGP | Mounted under chassis
13 | Rocker Switch (SPST) | Mini on/off toggle switch, panel-mount | Power | 1 | ~6 EGP | Main power cut-off on battery positive rail
14 | USB-B Cable | USB-A to USB-B, ~1.5 m, for programming and serial debug | Prototyping | 1 | ~85 EGP | Connects Mega to laptop for firmware upload
15 | M3 Standoffs, Screws, and Nuts Kit | Assorted M3 brass/nylon standoffs for board mounting | Mechanical | 1 | ~250 EGP | Kit; secures Mega and driver to chassis
TOTAL COMPONENTS |  |  |  | 22 | ~3,006 EGP

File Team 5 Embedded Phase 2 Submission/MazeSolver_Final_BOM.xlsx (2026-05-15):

Final BOM
Ref(s) | Component / Value | LCSC # | LCSC Link | KiCad Footprint | Symbol Source | SnapEDA Link | Status
▶ POWER
D1 | 1N5819 Schottky Diode | C145202 | https://www.lcsc.com/product-detail/C145202.html | Diode_SMD:D_SMA | Built-in KiCad |  | ✅ OK
J7 | Screw Terminal 2-pin 5.08mm | C84500 | https://www.lcsc.com/product-detail/C84500.html | TerminalBlock_Phoenix:TerminalBlock_Phoenix_MKDS-1,5-2-5.08_1x02_P5.08mm_Horizontal | Built-in KiCad |  | ✅ OK
U12 | AMS1117-5.0 LDO Regulator | C6187 | https://www.lcsc.com/product-detail/C6187.html | Package_TO_SOT_SMD:SOT-223-3_TabPin2 | Built-in KiCad |  | ✅ OK
U13 | AMS1117-3.3 LDO Regulator | C6186 | https://www.lcsc.com/product-detail/C6186.html | Package_TO_SOT_SMD:SOT-223-3_TabPin2 | Built-in KiCad |  | ✅ OK
C16, C17 | 10µF 25V X7R 0805 Bulk Cap | C3039694 | https://www.lcsc.com/product-detail/C3039694.html | Capacitor_SMD:C_0805_2012Metric | Built-in KiCad |  | ✅ OK
C18 | 100nF 0805 Decoupling Cap | C49678 | https://www.lcsc.com/product-detail/C49678.html | Capacitor_SMD:C_0805_2012Metric | Built-in KiCad |  | ✅ OK
▶ MCU
U11 | ATmega2560-16AU | C1792040 | https://www.lcsc.com/search?q=atmega2560 | Atmega:QFP50P1600X1600X120-100N | SnapEDA | https://www.snapeda.com/parts/ATMEGA2560-16AU/Microchip%20Technology/view-part/ | ✅ OK
Y2 | 16MHz Crystal SMD 3225 4-pin | C13774 | https://www.lcsc.com/product-detail/C13774.html | Crystal:Crystal_SMD_3225-4Pin_3.2x2.5mm | Built-in – use Crystal_GND24 |  | ✅ OK
C11, C12 | 22pF C0G 0805 Load Cap | C1804 | https://www.lcsc.com/product-detail/C1804.html | Capacitor_SMD:C_0805_2012Metric | Built-in KiCad |  | ✅ OK
C13, C14, C15 | 100nF 0805 Decoupling Cap | C49678 | https://www.lcsc.com/product-detail/C49678.html | Capacitor_SMD:C_0805_2012Metric | Built-in KiCad |  | ✅ OK
SW2 | Tactile Push Button Reset 6×6mm | C127506 | https://www.lcsc.com/product-detail/C127506.html | Button_Switch_SMD:SW_SPST_PTS645 | Built-in KiCad |  | ✅ OK
R35 | 1kΩ 0805 Resistor | C17513 | https://www.lcsc.com/product-detail/C17513.html | Resistor_SMD:R_0805_2012Metric | Built-in KiCad |  | ✅ OK
R36 | 2.2kΩ 0805 Resistor (changed from 2kΩ) | Search LCSC | https://www.lcsc.com/search?q=2.2k+0805+1%25 | Resistor_SMD:R_0805_2012Metric | Built-in KiCad |  | ✅ OK
J6 | ICSP 2×3 Pin Header 2.54mm | C65114 | https://www.lcsc.com/product-detail/C65114.html | Connector_PinHeader_2.54mm:PinHeader_2x03_P2.54mm_Vertical | Built-in KiCad |  | ✅ OK
▶ MOTOR DRIVER
U8 | L298N Dual H-Bridge Motor Driver | C19922 | https://www.lcsc.com/product-detail/C19922.html | L298N:TO127P2020X500X2100-15 | SnapEDA | https://www.snapeda.com/parts/L298N/STMicroelectronics/view-part/ | ✅ OK
C3 | 100nF 0805 Decoupling Cap (Vss) | C49678 | https://www.lcsc.com/product-detail/C49678.html | Capacitor_SMD:C_0805_2012Metric | Built-in KiCad |  | ✅ OK
D21–D28 | 1N5819 Flyback Diode (×8) | C145202 | https://www.lcsc.com/product-detail/C145202.html | Diode_SMD:D_SMA | Built-in KiCad |  | ✅ OK
J5 | Screw Terminal 4-pin 5.08mm | C395148 | https://www.lcsc.com/product-detail/C395148.html | TerminalBlock_Phoenix:TerminalBlock_Phoenix_MKDS-1,5-4-5.08_1x04_P5.08mm_Horizontal | Built-in KiCad |  | ✅ OK
▶ IR SENSORS & SCHMITT TRIGGER
U7,U9,U10,U14,U15 | TCRT5000 IR Reflective Sensor (×5) | C2984661 | https://www.lcsc.com/product-detail/C2984661.html | OptoDevice:Vishay_TCRT5000 | SnapEDA | https://www.snapeda.com/parts/TCRT5000/Vishay/view-part/ | ✅ OK
R17,R19,R20,R21,R22 | 220Ω 0805 LED Current Resistor (×5) [Updated from 100Ω] | C17557 | https://www.lcsc.com/product-detail/C17557.html | Resistor_SMD:R_0805_2012Metric | Built-in KiCad |  | ✅ OK
R23,R24,R25,R26,R27 | 10kΩ 0805 Pull-up Resistor (×5) | C17414 | https://www.lcsc.com/product-detail/C17414.html | Resistor_SMD:R_0805_2012Metric | Built-in KiCad |  | ✅ OK
U16 | SN74HC14DR Hex Schmitt-Trigger Inverter | C2861329 | https://www.lcsc.com/product-detail/C2861329.html | SN74HC14DR:SOIC127P600X175-14N | SnapEDA | https://www.snapeda.com/parts/SN74HC14DR/Texas%20Instruments/view-part/ | ✅ OK
C2 | 100nF 0805 Decoupling Cap (VCC) | C49678 | https://www.lcsc.com/product-detail/C49678.html | Capacitor_SMD:C_0805_2012Metric | Built-in KiCad |  | ✅ OK
D15–D19 | Red LED 0805 Status (×5) | C2286 | https://www.lcsc.com/product-detail/C2286.html | LED_SMD:LED_0805_2012Metric | Built-in KiCad |  | ✅ OK
D20 | Green LED 0805 Power | C2293 | https://www.lcsc.com/product-detail/C2293.html | LED_SMD:LED_0805_2012Metric | Built-in KiCad |  | ✅ OK
R28–R33 | 1kΩ 0805 LED Resistor (×6) | C17513 | https://www.lcsc.com/product-detail/C17513.html | Resistor_SMD:R_0805_2012Metric | Built-in KiCad |  | ✅ OK
▶ BLUETOOTH / CC2540
U1 | CC2540F256RHAR BLE SoC | C22649 | https://www.lcsc.com/product-detail/C22649.html | CC2540:QFN50P600X600X100-41N | SnapEDA | https://www.snapeda.com/parts/CC2540F256RHAR/Texas%20Instruments/view-part/ | ✅ OK
R34 | 56kΩ 0805 Bias Resistor (RBIAS) [User link: C137509] | C137509 | https://www.lcsc.com/product-detail/C137509.html | Resistor_SMD:R_0805_2012Metric | Built-in KiCad |  | ✅ OK
Y4 | 32MHz Crystal SMD 3225 4-pin | C7275125 | https://www.lcsc.com/product-detail/C7275125.html | Crystal:Crystal_SMD_3225-4Pin_3.2x2.5mm | Built-in – use Crystal_GND24 |  | ✅ OK
Y3 | 32.768kHz Crystal SMD 3215 2-pin | C390740 | https://www.lcsc.com/product-detail/C390740.html | Crystal:Crystal_SMD_3215-2Pin_3.2x1.5mm | Built-in KiCad |  | ✅ OK
C20, C21 | 15pF C0G 0805 RTC Load Cap (×2) [User link: C107110] | C107110 | https://www.lcsc.com/product-detail/C107110.html | Capacitor_SMD:C_0805_2012Metric | Built-in KiCad |  | ✅ OK
C27, C28 | 12pF C0G 0805 XOSC Load Cap (×2) [User link: C107108] | C107108 | https://www.lcsc.com/product-detail/C107108.html | Capacitor_SMD:C_0805_2012Metric | Built-in KiCad |  | ✅ OK
C22, C25 | 1pF C0G 0402 RF Cap (×2) [User link: C2299956] | C2299956 | https://www.lcsc.com/product-detail/C2299956.html | Capacitor_SMD:C_0402_1005Metric | Built-in KiCad |  | ✅ OK
C23 | 1.2pF C0G 0402 RF Cap [User link: C42432085] | C42432085 | https://www.lcsc.com/product-detail/C42432085.html | Capacitor_SMD:C_0402_1005Metric | Built-in KiCad |  | ✅ OK
C24, C26 | 1.6pF C0G 0402 RF Cap (×2) [User link: C17620754] | C17620754 | https://www.lcsc.com/product-detail/C17620754.html | Capacitor_SMD:C_0402_1005Metric | Built-in KiCad |  | ✅ OK
C29 + AVDD pins | 100nF 0805 Decoupling (×8 total) [Was 12pF – CRITICAL FIX] | C49678 | https://www.lcsc.com/product-detail/C49678.html | Capacitor_SMD:C_0805_2012Metric | Built-in KiCad |  | ✅ OK
L1 | 1.2nH 0402 RF Inductor [User link: C395097] | C395097 | https://www.lcsc.com/product-detail/C395097.html | Inductor_SMD:L_0402_1005Metric | Built-in KiCad |  | ✅ OK
L4 | 1.8nH 0402 RF Inductor [User substituting 1.8nH for 2nH – link: C1036] | C1036 | https://www.lcsc.com/product-detail/C1036.html | Inductor_SMD:L_0402_1005Metric | Built-in KiCad |  | ✅ OK
L2, L3 | 2.2nH 0402 RF Inductor (×2) [User link: C18221258] | C18221258 | https://www.lcsc.com/product-detail/C18221258.html | Inductor_SMD:L_0402_1005Metric | Built-in KiCad |  | ✅ OK
U2 | PCB Trace Antenna (feed point) | N/A | https://www.ti.com/lit/an/swra117d/swra117d.pdf | Built in | Built in |  | ✅ OK
Guide

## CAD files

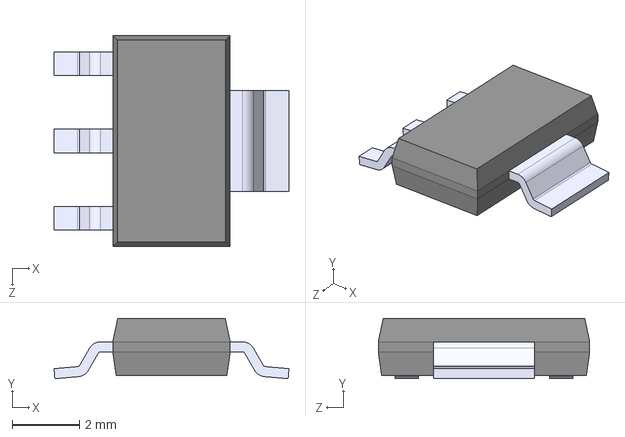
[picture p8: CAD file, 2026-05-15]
Team 5 Embedded Phase 2 Submission/Components/AMS1117-3/AMS1117-3.3.step
7.00 x 1.80 x 6.30 mm

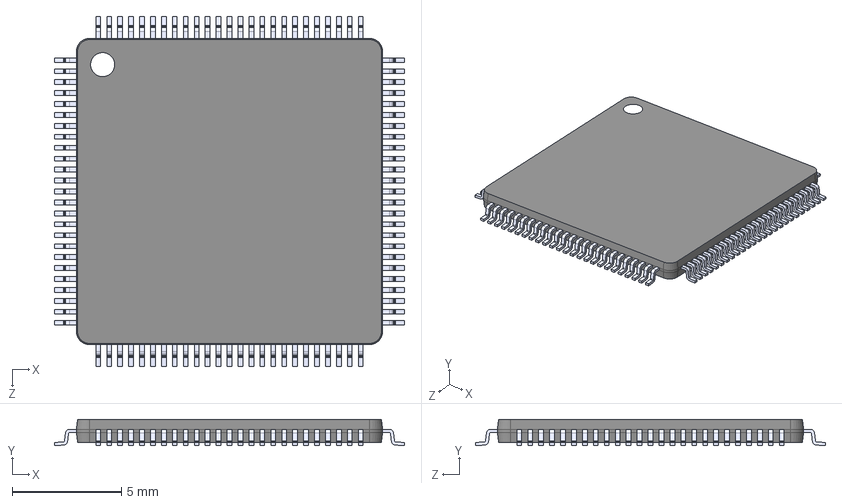
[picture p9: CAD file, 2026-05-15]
Team 5 Embedded Phase 2 Submission/Components/ATmega2560-16AU/ATmega2560-16AU.step
16.0 x 1.20 x 16.0 mm

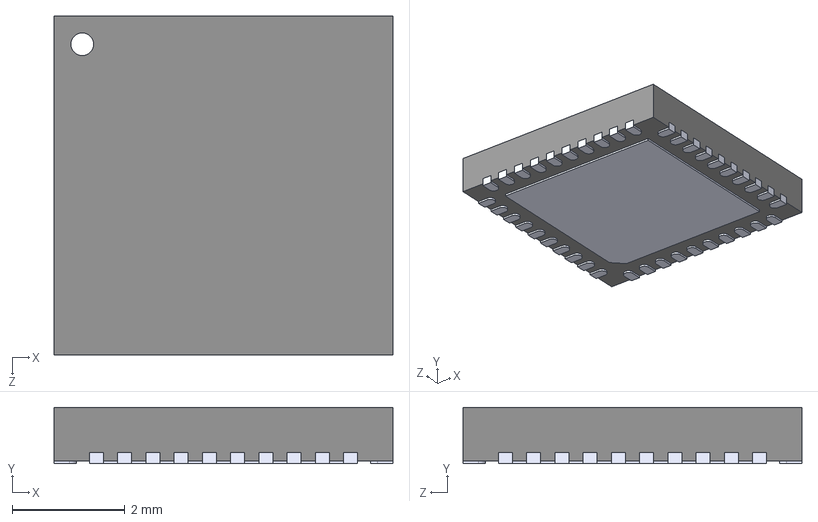
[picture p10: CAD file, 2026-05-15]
Team 5 Embedded Phase 2 Submission/Components/CC2540F256RHAR/CC2540F256RHAR.step
6.00 x 1.00 x 6.00 mm

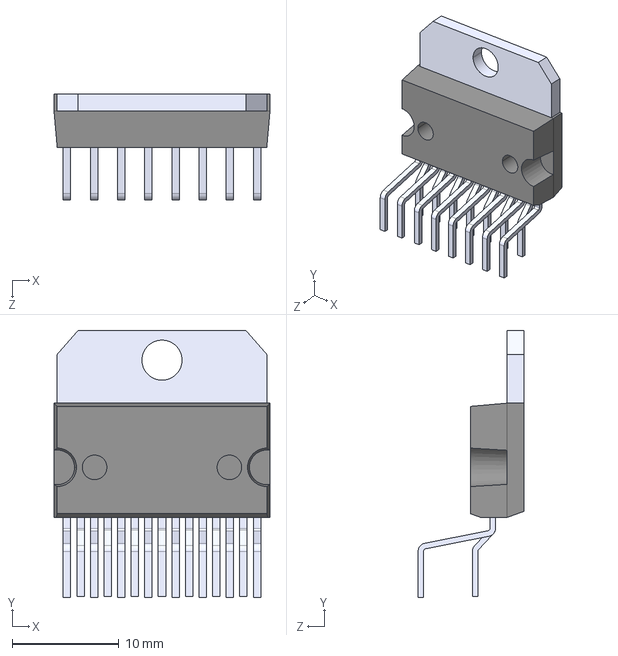
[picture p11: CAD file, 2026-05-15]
Team 5 Embedded Phase 2 Submission/Components/L298N/L298N.step
20.2 x 25.0 x 9.89 mm

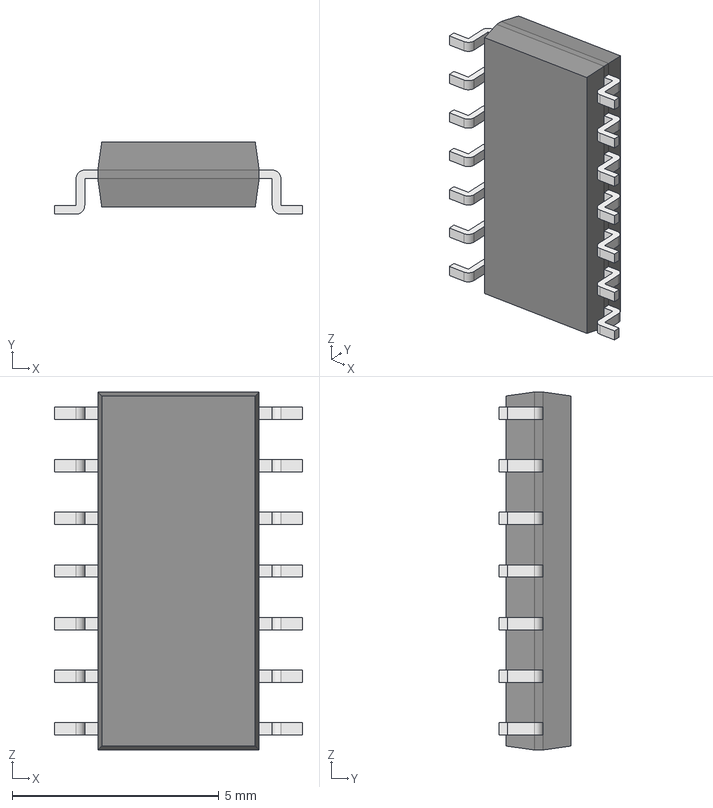
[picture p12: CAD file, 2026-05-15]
Team 5 Embedded Phase 2 Submission/Components/SN74HC14DR/SN74HC14DR.step
6.00 x 1.75 x 8.65 mm
Body001 (Mirror #1) x 7
XY-plane x 12
X-axis x 12

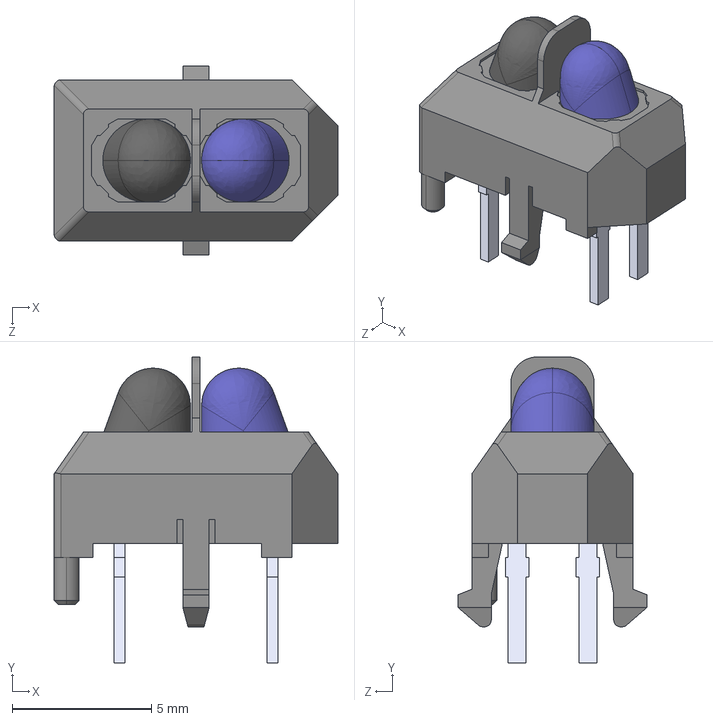
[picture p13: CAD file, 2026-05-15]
Team 5 Embedded Phase 2 Submission/Components/TCRT5000/TCRT5000.step
10.2 x 11.0 x 6.80 mm

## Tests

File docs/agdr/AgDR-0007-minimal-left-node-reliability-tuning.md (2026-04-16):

---
id: AgDR-0007
timestamp: 2026-03-18T00:00:00Z
agent: cursor
model: GPT-5.4
trigger: user-prompt
status: executed
---

# Minimal Left-Node Reliability Tuning

> In the context of an already partially working `working_code.ino` sketch for Phase 0, facing missed or late left turns at `T` and `+` intersections on the team maze, I decided to keep the existing follower structure and apply a minimal behavior refinement that broadens intersection classification for wide nodes, preserves pending node intent through brief all-black crossings, and trims turn-entry timing, to improve reliability without destabilizing the current 70%-effective behavior.

## Context
- Phase 0 in `project_description.md` requires one successful training traversal and one successful solving traversal, with wireless deferred.
- The current sketch already follows the line reasonably well, so a large rewrite would risk losing working behavior.
- The observed issue is specific: some left turns at `T` and `+` intersections are missed or entered too late.
- In the current sketch, `onCount == 5` becomes `DEC_E`, which is temporarily downgraded to straight travel during training, and committed turns include a forward creep before spinning.

## Options Considered
| Option | Pros | Cons |
|---|---|---|
| Replace the follower with a new multi-state node handler immediately | Most structured long-term approach, closer to a full FSM | Too much change for a sketch that already works acceptably, higher regression risk |
| Keep the existing structure and minimally tune classification plus turn timing | Smallest risk, directly targets the reported failure, easy to tune on hardware | Less architecturally clean, still relies on heuristic thresholds |

## Decision
Chosen: **Keep the current structure and apply a minimal reliability tuning pass**, by extracting a small intersection-classification helper, remembering pending node intent across brief all-black spans, and reducing the pre-spin forward creep and intersection lockout, because this directly addresses the missed-left symptom while preserving the rest of the sketch's working behavior.

## Consequences
- Wide `+` intersections should stop being mistaken for straight-only travel when all sensors briefly see black.
- Left turns should begin earlier, reducing overshoot into the white area beside the branch.
- The sketch remains easy to compare against the previous working baseline because the overall control flow is unchanged.
- If this tuning is still insufficient on hardware, the next step should be a true follow/node/turn FSM rather than more ad-hoc condition growth.

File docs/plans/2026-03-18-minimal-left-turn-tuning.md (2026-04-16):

# Minimal Left-Turn Tuning Implementation Plan

> **For Claude:** REQUIRED SUB-SKILL: Use superpowers:executing-plans to implement this plan task-by-task.

**Goal:** Improve reliability of missed left turns in `working_code.ino` with the smallest safe behavior change.

**Architecture:** Keep the current follower structure, use the existing `UNIT_TEST` compatibility path to pin down one missed-left regression, then minimally tune pending intersection memory and left-turn execution timing. Avoid FSM rewrites or unrelated motor-control changes.

**Tech Stack:** Arduino `.ino` sketch, `g++` host-side regression test via `#define UNIT_TEST`, Markdown docs.

---

### Task 1: Reproduce the missed-left behavior in a host-side test

**Files:**
- Modify: `working_code.ino`
- Create: `left_turn_regression_test.cpp`

**Step 1: Write the failing test**

Create a small host-side test that includes `working_code.ino` in `UNIT_TEST` mode and verifies that once a left intersection has been detected, a brief narrower pattern does not immediately erase that pending left intent before the junction is fully crossed.

**Step 2: Run test to verify it fails**

Run: `g++ -std=c++17 left_turn_regression_test.cpp -o left_turn_regression_test && ./left_turn_regression_test`

Expected: FAIL because the current logic resets pending intent too aggressively.

**Step 3: Write minimal implementation**

Adjust the pending-intersection retention rule so committed left/right intent survives short low-sensor-count windows while the robot is still crossing the node.

**Step 4: Run test to verify it passes**

Run: `g++ -std=c++17 left_turn_regression_test.cpp -o left_turn_regression_test && ./left_turn_regression_test`

Expected: PASS

### Task 2: Improve the physical left-turn commitment

**Files:**
- Modify: `working_code.ino`

**Step 1: Write the failing test**

Add one more host-side assertion for a wide-node left classification pattern if needed.

**Step 2: Run test to verify it fails**

Use the same `g++` command and confirm the new expectation fails for the right reason.

**Step 3: Write minimal implementation**

Slightly increase left/right turn commitment by tuning forward creep and spin settle timing without changing the overall control structure.

**Step 4: Run test to verify it passes**

Use the same `g++` command and confirm all assertions pass.

### Task 3: Verify and document

**Files:**
- Modify: `working_code.ino`
- Check: `docs/agdr/AgDR-0007-minimal-left-node-reliability-tuning.md`

**Step 1: Run the regression test**

Run: `g++ -std=c++17 left_turn_regression_test.cpp -o left_turn_regression_test && ./left_turn_regression_test`

Expected: PASS

**Step 2: Check edited files for issues**

Review the changed sketch for consistency and run lints/diagnostics if available.

**Step 3: Hardware validation**

Re-run the car on the same maze and specifically watch the two previously missed left nodes.

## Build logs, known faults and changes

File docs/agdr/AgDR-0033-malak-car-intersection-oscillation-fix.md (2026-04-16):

---
id: AgDR-0033
timestamp: 2026-04-02T12:00:00Z
agent: cursor
model: composer
trigger: user-prompt
status: executed
---

# Malak car_code: fix intersection metastable oscillation

> In the context of line-following maze code in `Malak's Stuff/car_code.ino`, facing repeated node handling and forward/stop hunting at turns, I decided to relax `isCentered`, add a post-node `nodeDetected` cooldown, and skip all-white dead-end probing while `inIntersection`, to achieve stable exit from junctions without re-triggering the same node, accepting a short blind window where a second junction very close in time could be missed.

## Context
- `isCentered` required far sensors white while inner sensors straddled the line; at real junctions far sensors often still see branch lines, so exit from `inIntersection` was unreliable or flickery.
- After a brief `isCentered` true, `nodeDetected` could fire again immediately because far sensors still saw the same junction.
- `handleDeadEndOrGap` ran before the intersection exit path and could add forward probes during white gaps, fighting `followLine` stop behavior.

## Options Considered
| Option | Pros | Cons |
|---|---|---|
| **A — Relax `isCentered` only** | Simple, fixes stuck `inIntersection` | May still re-detect same node if far sensors see black |
| **B — Cooldown on `nodeDetected` only** | Blocks duplicate node cycles | Does not fix never clearing `inIntersection` if `isCentered` too strict |
| **C — A + B + skip dead-end probe while `inIntersection`** | Addresses all three mechanisms observed | Tunable `postNodeCooldownMs`; very tight adjacent nodes in time could be skipped once |

## Decision
Chosen: **Option C**, because the failure mode was a combination of strict exit criteria, immediate re-detection, and dead-end probing order; fixing one layer alone leaves the others able to oscillate.

## Consequences
- `isCentered` uses center + near sensors only for alignment exit.
- `ignoreNodeDetectionUntil` gates `nodeDetected` for `postNodeCooldownMs` after each completed node action (including dead-end 180).
- Dead-end forward probe does not run while `inIntersection` is true.

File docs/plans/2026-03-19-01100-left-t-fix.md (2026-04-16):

# 01100 Left-T Fix Implementation Plan

> **For Claude:** REQUIRED SUB-SKILL: Use superpowers:executing-plans to implement this plan task-by-task.

**Goal:** Make true left Ts visible when the sensor sequence is `00100 -> 01100 -> 00100` and `s0` never fires.

**Architecture:** Keep the controller self-contained in `working_code.ino`, preserve the current `s0Recently` and post-left-assist gates, and add one small piece of previous-sample state so `01100` can count as a left junction immediately after a clean centered approach. Drive the change with a failing regression test first, then make the smallest classifier update needed to pass it.

**Tech Stack:** Arduino-style C++ in a single `.ino` file with host-side C++ regression tests.

---

### Task 1: Add the failing regression

**Files:**
- Modify: `left_turn_regression_test.cpp`
- Test: `left_turn_regression_test.cpp`

**Step 1: Write the failing test**

```cpp
static void test_centered_approach_then_01100_commits_left_without_s0() {
  resetDecisionStateForTest();

  setTestSensorPattern(0, 0, 1, 0, 0);
  expectEqual(decideDirectionFull(), DEC_S, "clean centered approach should still follow straight");

  setTestMillis(20);
  setTestSensorPattern(0, 1, 1, 0, 0);
  expectEqual(
    decideDirectionFull(),
    DEC_SL,
    "01100 immediately after a centered approach should commit the left T even without s0 evidence"
  );
}
```

**Step 2: Run test to verify it fails**

Run: `g++ -std=c++17 left_turn_regression_test.cpp -o /tmp/left_turn_regression_test && /tmp/left_turn_regression_test`

Expected: FAIL on the new test because current logic returns `DEC_S` for ungated `01100`.

### Task 2: Implement the minimal classifier state

**Files:**
- Modify: `working_code.ino`
- Test: `left_turn_regression_test.cpp`

**Step 1: Write minimal implementation**

```cpp
bool previousPatternWasCentered = false;

// inside decideDirectionFull()
bool previousCenteredApproach = previousPatternWasCentered;
bool currentPatternIsCentered = s2 && !s0 && !s1 && !s3 && !s4;

bool narrowLeftStem = (s1 && s2 && !s3 && !s4) &&
                      (s0 || s0Recently || postLeftCloseJunctionAssistActive() || previousCenteredApproach);

previousPatternWasCentered = currentPatternIsCentered;
```

**Step 2: Run test to verify it passes**

Run: `g++ -std=c++17 left_turn_regression_test.cpp -o /tmp/left_turn_regression_test && /tmp/left_turn_regression_test`

Expected: PASS.

### Task 3: Verify stale `01100` still stays straight

**Files:**
- Test: `close_left_regression_test.cpp`

**Step 1: Run the targeted stale-01100 regression**

Run: `g++ -std=c++17 close_left_regression_test.cpp -o /tmp/close_left_regression_test && /tmp/close_left_regression_test`

Expected: PASS, especially the stale `01100` case that does not include an immediate centered approach.

### Task 4: Final verification

**Files:**
- Modify: `working_code.ino`
- Modify: `left_turn_regression_test.cpp`
- Create: `docs/agdr/AgDR-0027-center-approach-01100-left-commit.md`
- Create: `docs/plans/2026-03-19-01100-left-t-design.md`
- Create: `docs/plans/2026-03-19-01100-left-t-fix.md`

**Step 1: Run lint/diagnostic check**

Run: `ReadLints` on the edited files.

**Step 2: Re-run both regression binaries**

Run:
- `g++ -std=c++17 left_turn_regression_test.cpp -o /tmp/left_turn_regression_test && /tmp/left_turn_regression_test`
- `g++ -std=c++17 close_left_regression_test.cpp -o /tmp/close_left_regression_test && /tmp/close_left_regression_test`

Expected: both PASS with clean output.

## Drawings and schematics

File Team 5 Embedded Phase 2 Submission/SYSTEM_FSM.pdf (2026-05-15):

## setup() / System Boot

### WAIT_COMMAND

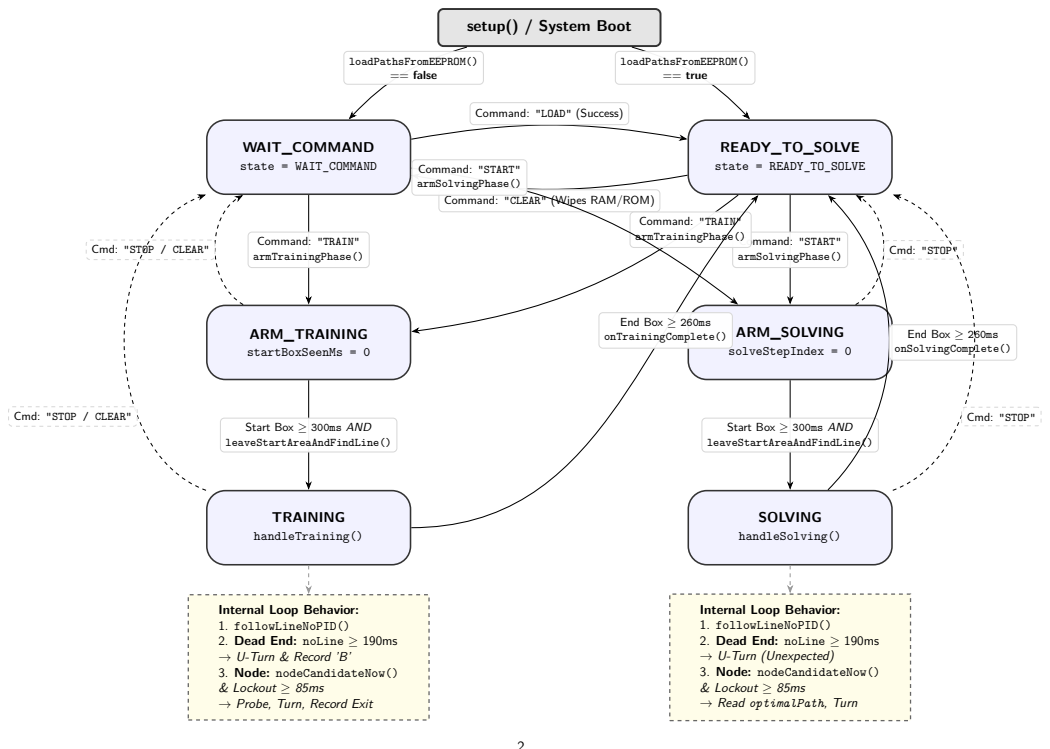
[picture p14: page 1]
state = WAIT_COMMAND; READY_TO_SOLVE state = READY_TO_SOLVE; ARM_TRAINING startBoxSeenMs = 0; ARM_SOLVING solveStepIndex = 0; TRAINING handleTraining(); SOLVING handleSolving(); loadPathsFromEEPROM() == false; loadPathsFromEEPROM() == true; Command: "TRAIN" armTrainingPhase(); Command: "START" armSolvingPhase(); End Box → 260ms; onTrainingComplete(); onSolvingComplete(); Cmd: "STOP"

Command: "LOAD" (Success)

Command: "START"
armSolvingPhase()
Command: "CLEAR" (Wipes RAM/ROM)

Cmd: "STOP / CLEAR"

Start Box → 300ms AND
leaveStartAreaAndFindLine()

Internal Loop Behavior:
1. followLineNoPID()
2. Dead End: noLine → 190ms
↑ U-Turn & Record ’B’
3. Node: nodeCandidateNow()
& Lockout → 85ms
↑ Probe, Turn, Record Exit

↑ U-Turn (Unexpected)
↑ Read optimalPath, Turn

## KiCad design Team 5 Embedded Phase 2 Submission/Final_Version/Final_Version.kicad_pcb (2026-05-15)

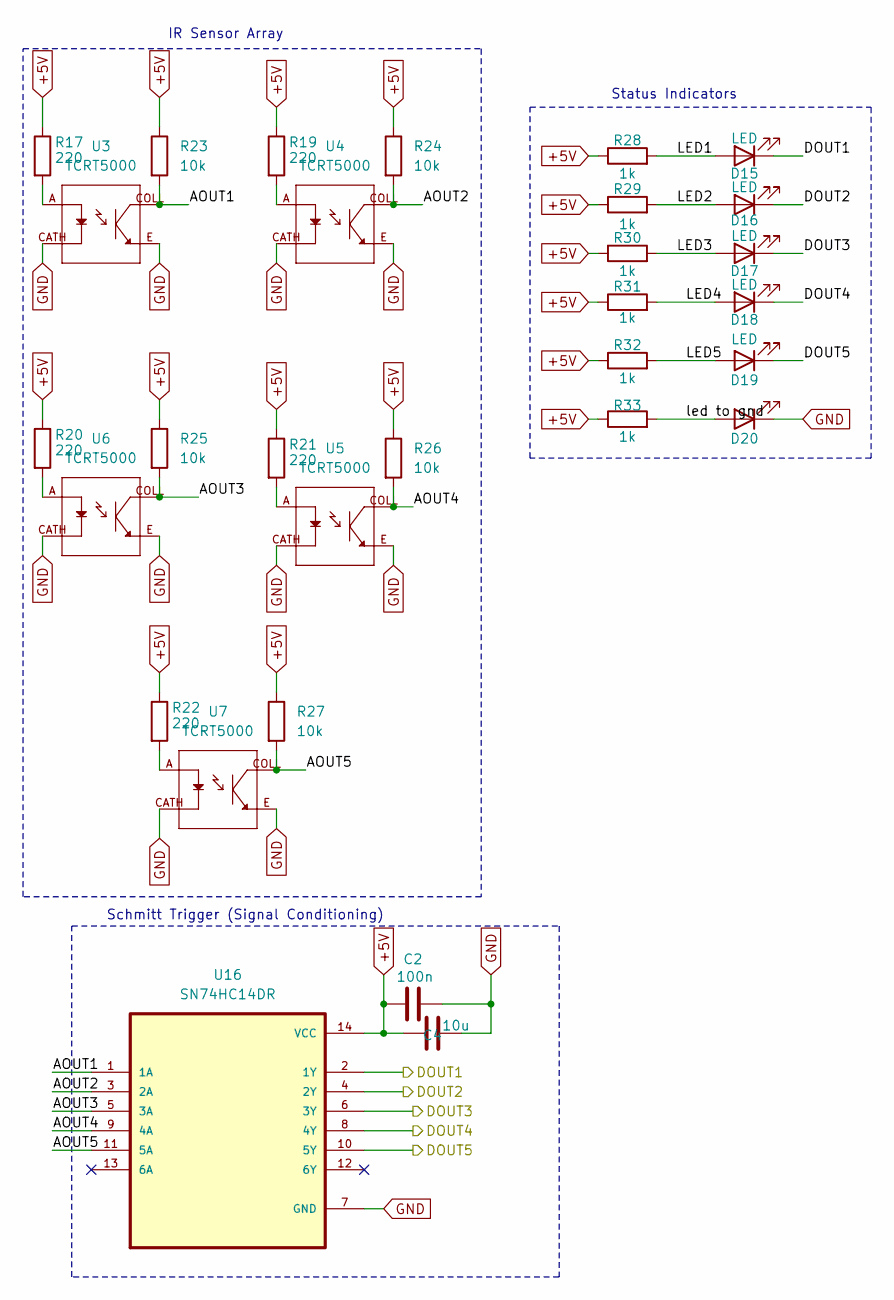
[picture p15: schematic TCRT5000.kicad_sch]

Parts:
C2: 100n; C_0805_2012Metric
C4: 10u; C_0805_2012Metric
D15, D16, D17, D18, D19, D20: LED; LED_0805_2012Metric
R17, R19, R20, R21, R22: 220; R_0805_2012Metric
R23, R24, R25, R26, R27: 10k; R_0805_2012Metric
R28, R29, R30, R31, R32, R33: 1k; R_0805_2012Metric
U3, U4, U5, U6, U7: TCRT5000; OPTO_TCRT5000; PARTREV 1.7
U16: SN74HC14DR; SOIC127P600X175-14N

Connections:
+5V: C2.1, C4.1, R17.1, R19.1, R20.1, R21.1, R22.1, R23.1, R24.1, R25.1, R26.1, R27.1, R28.1, R29.1, R30.1, R31.1, R32.1, R33.1, U16.14 (VCC); also elsewhere on the board
/TCRT5000/AOUT1: R23.2, U3.COLL, U16.1 (1A)
/TCRT5000/AOUT2: R24.2, U4.COLL, U16.3 (2A)
/TCRT5000/AOUT3: R25.2, U6.COLL, U16.5 (3A)
/TCRT5000/AOUT4: R26.2, U5.COLL, U16.9 (4A)
/TCRT5000/AOUT5: R27.2, U7.COLL, U16.11 (5A)
/TCRT5000/DOUT1: D15.1 (K), U16.2 (1Y); also elsewhere on the board
/TCRT5000/DOUT2: D16.1 (K), U16.4 (2Y); also elsewhere on the board
/TCRT5000/DOUT3: D17.1 (K), U16.6 (3Y); also elsewhere on the board
/TCRT5000/DOUT4: D18.1 (K), U16.8 (4Y); also elsewhere on the board
/TCRT5000/DOUT5: D19.1 (K), U16.10 (5Y); also elsewhere on the board
/TCRT5000/LED1: D15.2 (A), R28.2
/TCRT5000/LED2: D16.2 (A), R29.2
/TCRT5000/LED3: D17.2 (A), R30.2
/TCRT5000/LED4: D18.2 (A), R31.2
/TCRT5000/LED5: D19.2 (A), R32.2
/TCRT5000/led to gnd: D20.2 (A), R33.2
GND: C2.2, C4.2, D20.1 (K), U3.CATH, U3.E, U4.CATH, U4.E, U5.CATH, U5.E, U6.CATH, U6.E, U7.CATH, U7.E, U16.7 (GND); also elsewhere on the board
unnamed: R17.2, U3.A
unnamed: R19.2, U4.A
unnamed: R20.2, U6.A
unnamed: R21.2, U5.A
unnamed: R22.2, U7.A

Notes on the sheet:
IR Sensor Array
Status Indicators
Schmitt Trigger (Signal Conditioning)

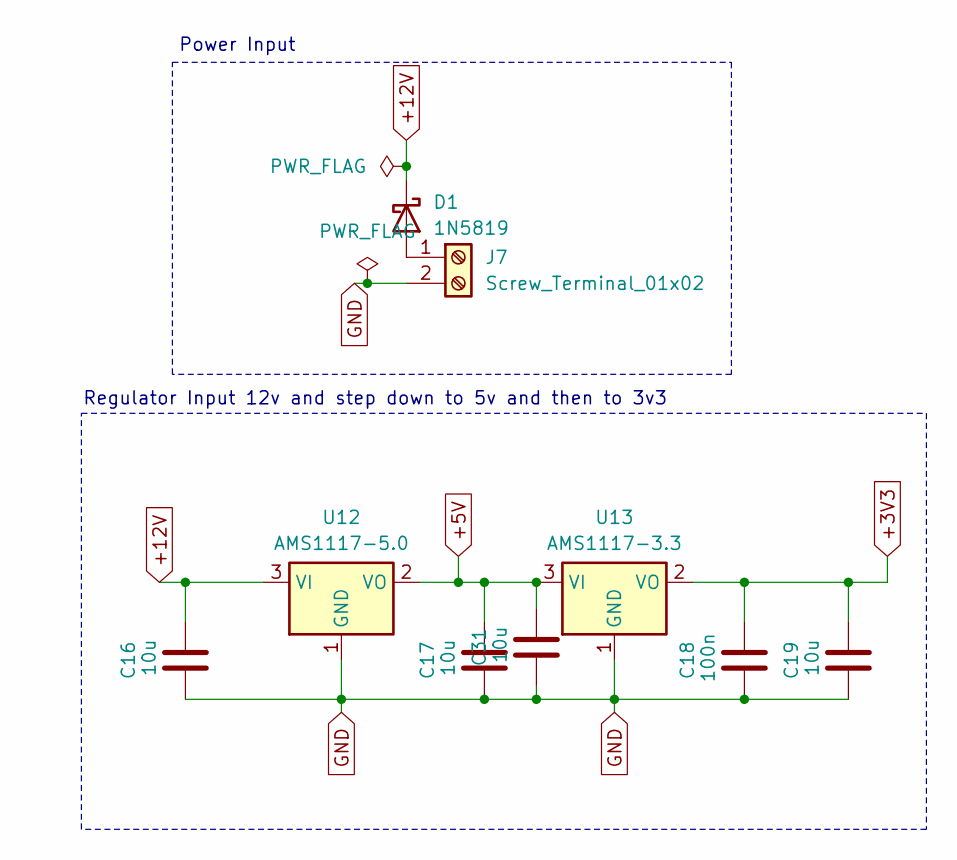
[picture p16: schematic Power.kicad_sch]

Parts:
C16, C17, C19, C31: 10u; C_0805_2012Metric
C18: 100n; C_0805_2012Metric
D1: 1N5819; D_SMA
J7: Screw_Terminal_01x02; TerminalBlock_Phoenix_MKDS-1,5-2-5.08_1x02_P5.08mm_Horizont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
U12: AMS1117-5.0; SOT-223-3_TabPin2
U13: AMS1117-3.3; SOT-223-3_TabPin2

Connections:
+3V3: C18.2, C19.2, U13.2 (VO); also elsewhere on the board
+5V: C17.2, C31.2, U12.2 (VO), U13.3 (VI); also elsewhere on the board
+12V: C16.2, D1.1 (K), U12.3 (VI); also elsewhere on the board
GND: C16.1, C17.1, C18.1, C19.1, C31.1, J7.2, U12.1 (GND), U13.1 (GND); also elsewhere on the board
unnamed: D1.2 (A), J7.1

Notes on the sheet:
Power Input
Regulator Input 12v and step down to 5v and then to 3v3

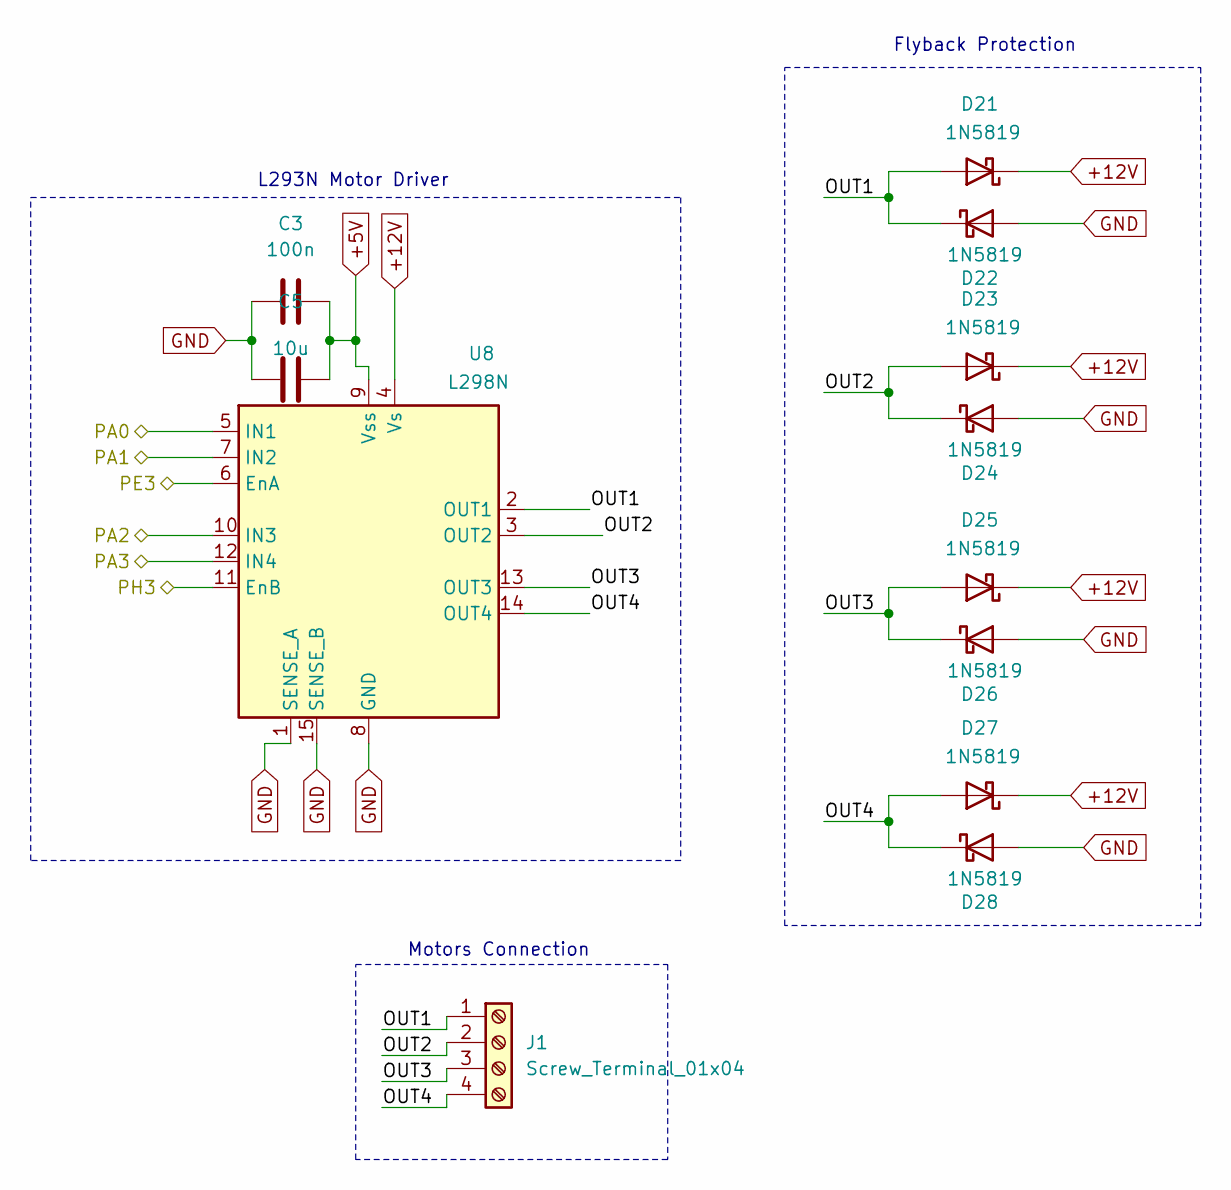
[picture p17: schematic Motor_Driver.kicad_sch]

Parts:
C3: 100n
C5: 10u
D21, D22, D23, D24, D25, D26, D27, D28: 1N5819; D_SMA
J1: Screw_Terminal_01x04; TerminalBlock_Phoenix_MKDS-1,5-4-5.08_1x04_P5.08mm_Horizont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
U8: L298N; TO127P2020X500X2100-15

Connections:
+5V: C3.2, C5.2, U8.9 (Vss); also elsewhere on the board
+12V: D21.1 (K), D23.1 (K), D25.1 (K), D27.1 (K), U8.4 (Vs); also elsewhere on the board
/MCU/PA0: U8.5 (IN1); also elsewhere on the board
/MCU/PA1: U8.7 (IN2); also elsewhere on the board
/MCU/PA2: U8.10 (IN3); also elsewhere on the board
/MCU/PA3: U8.12 (IN4); also elsewhere on the board
/MCU/PE3: U8.6 (EnA); also elsewhere on the board
/MCU/PH3: U8.11 (EnB); also elsewhere on the board
/Motor Driver/OUT1: D21.2 (A), D22.1 (K), J1.1, U8.2 (OUT1)
/Motor Driver/OUT2: D23.2 (A), D24.1 (K), J1.2, U8.3 (OUT2)
/Motor Driver/OUT3: D25.2 (A), D26.1 (K), J1.3, U8.13 (OUT3)
/Motor Driver/OUT4: D27.2 (A), D28.1 (K), J1.4, U8.14 (OUT4)
GND: C3.1, C5.1, D22.2 (A), D24.2 (A), D26.2 (A), D28.2 (A), U8.1 (SENSE_A), U8.8 (GND), U8.15 (SENSE_B); also elsewhere on the board

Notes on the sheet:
Flyback Protection
Motors Connection
L293N Motor Driver

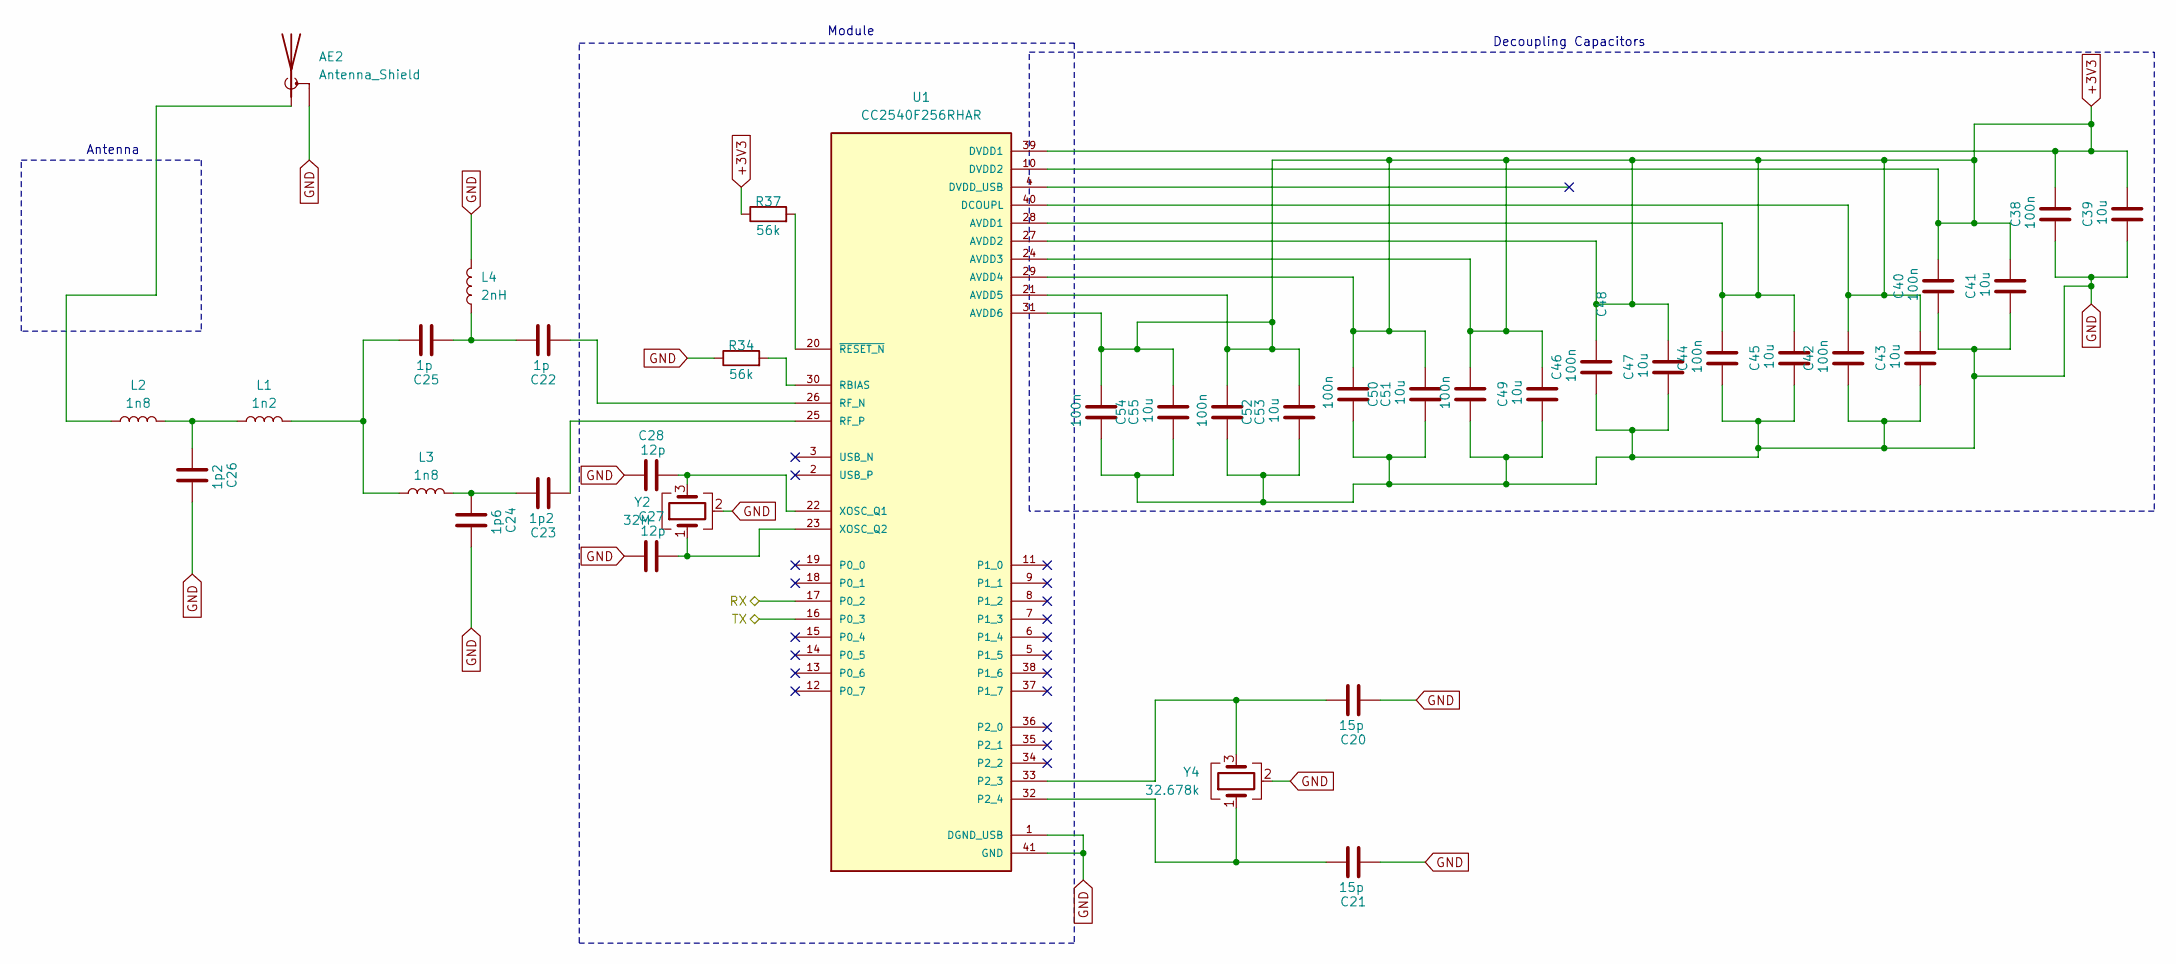
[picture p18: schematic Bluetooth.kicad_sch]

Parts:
AE2: Antenna_Shield; Texas_SWRA117D_2.4GHz_Right
C20, C21: 15p; C_0805_2012Metric
C22, C25: 1p; C_0805_2012Metric
C23, C26: 1p2; C_0805_2012Metric
C24: 1p6; C_0402_1005Metric
C27, C28: 12p; C_0805_2012Metric
C38, C40, C42, C44, C46, C48, C50, C52, C54: 100n; C_0805_2012Metric
C39, C41, C43, C45, C47, C49, C51, C53, C55: 10u; C_0805_2012Metric
L1: 1n2; L_0805_2012Metric
L2, L3: 1n8; L_0805_2012Metric
L4: 2nH; L_0402_1005Metric
R34, R37: 56k; R_0805_2012Metric
U1: CC2540F256RHAR; QFN50P600X600X100-41N
Y2: 32M; Crystal_SMD_3225-4Pin_3.2x2.5mm
Y4: 32.678k; Crystal_SMD_3225-4Pin_3.2x2.5mm

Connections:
+3V3: C38.2, C39.2, C40.2, C41.2, C42.2, C43.2, C44.2, C45.2, C46.2, C47.2, C48.2, C49.2, C50.2, C51.2, C52.2, C53.2, C54.2, C55.2, R37.1, U1.10 (DVDD2), U1.21 (AVDD5), U1.24 (AVDD3), U1.27 (AVDD2), U1.28 (AVDD1), U1.29 (AVDD4), U1.31 (AVDD6), U1.39 (DVDD1), U1.40 (DCOUPL); also elsewhere on the board
/Bluetooth/RX: U1.17 (P0_2); also elsewhere on the board
/Bluetooth/TX: U1.16 (P0_3); also elsewhere on the board
GND: AE2.2 (Shield), C20.1, C21.1, C24.2, C26.2, C27.1, C28.1, C38.1, C39.1, C40.1, C41.1, C42.1, C43.1, C44.1, C45.1, C46.1, C47.1, C48.1, C49.1, C50.1, C51.1, C52.1, C53.1, C54.1, C55.1, L4.2, R34.1, U1.1 (DGND_USB), U1.41 (GND), Y2.2 (G), Y2.4 (G), Y4.2 (G), Y4.4 (G); also elsewhere on the board
unnamed: AE2.1 (A), L2.1
unnamed: C22.2, C25.1, L4.1
unnamed: C23.2, C24.1, L3.2
unnamed: C25.2, L1.2, L3.1
unnamed: C26.1, L1.1, L2.2
unnamed: C20.2, U1.33 (P2_3), Y4.3
unnamed: C21.2, U1.32 (P2_4), Y4.1
unnamed: R34.2, U1.30 (RBIAS)
unnamed: C22.1, U1.26 (RF_N)
unnamed: C23.1, U1.25 (RF_P)
unnamed: C28.2, U1.22 (XOSC_Q1), Y2.3
unnamed: C27.2, U1.23 (XOSC_Q2), Y2.1
unnamed: R37.2, U1.20 (~RESET_N)

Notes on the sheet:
Module
Antenna
Decoupling Capacitors

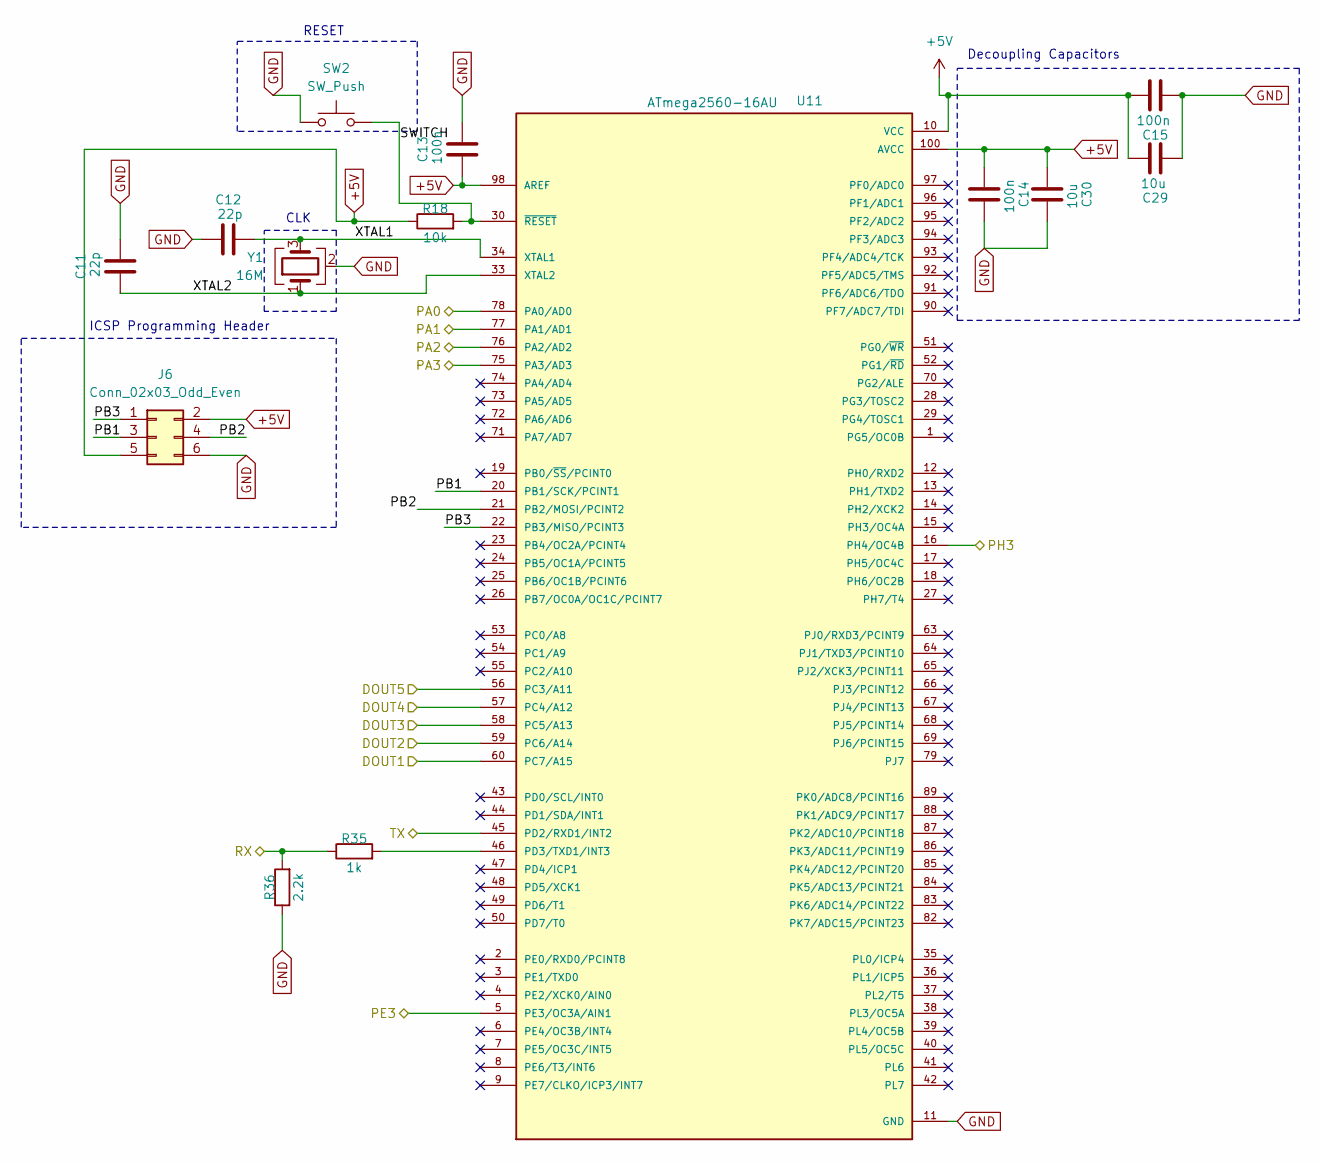
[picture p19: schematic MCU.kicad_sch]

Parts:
C11, C12: 22p; C_0805_2012Metric
C13, C14, C15: 100n; C_0805_2012Metric
C29, C30: 10u; C_0805_2012Metric
J6: Conn_02x03_Odd_Even; PinHeader_2x03_P2.54mm_Vertical
R18: 10k; R_0805_2012Metric
R35: 1k; R_0805_2012Metric
R36: 2.2k; R_0805_2012Metric
SW2: SW_Push; SW_SPST_PTS645Sx43SMTR92
U11: ATmega2560-16AU; QFP50P1600X1600X120-100N; PARTREV DS40002211A-05/2020
Y1: 16M

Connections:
+5V: C13.1, C14.1, C15.2, C29.2, C30.1, J6.2, J6.5, R18.1, U11.10 (VCC), U11.31 (VCC), U11.61 (VCC), U11.80 (VCC), U11.98 (AREF), U11.100 (AVCC); also elsewhere on the board
/Bluetooth/RX: R35.1, R36.2; also elsewhere on the board
/Bluetooth/TX: U11.45 (PD2/RXD1/INT2); also elsewhere on the board
/MCU/PA0: U11.78 (PA0/AD0); also elsewhere on the board
/MCU/PA1: U11.77 (PA1/AD1); also elsewhere on the board
/MCU/PA2: U11.76 (PA2/AD2); also elsewhere on the board
/MCU/PA3: U11.75 (PA3/AD3); also elsewhere on the board
/MCU/PB1: J6.3, U11.20 (PB1/SCK/PCINT1)
/MCU/PB2: J6.4, U11.21 (PB2/MOSI/PCINT2)
/MCU/PB3: J6.1, U11.22 (PB3/MISO/PCINT3)
/MCU/PE3: U11.5 (PE3/OC3A/AIN1); also elsewhere on the board
/MCU/PH3: U11.16 (PH4/OC4B); also elsewhere on the board
/MCU/SWITCH: R18.2, SW2.2, U11.30 (~RESET)
/MCU/XTAL1: C12.2, U11.34 (XTAL1), Y1.3
/MCU/XTAL2: C11.1, U11.33 (XTAL2), Y1.1
/TCRT5000/DOUT1: U11.60 (PC7/A15); also elsewhere on the board
/TCRT5000/DOUT2: U11.59 (PC6/A14); also elsewhere on the board
/TCRT5000/DOUT3: U11.58 (PC5/A13); also elsewhere on the board
/TCRT5000/DOUT4: U11.57 (PC4/A12); also elsewhere on the board
/TCRT5000/DOUT5: U11.56 (PC3/A11); also elsewhere on the board
GND: C11.2, C12.1, C13.2, C14.2, C15.1, C29.1, C30.2, J6.6, R36.1, SW2.1, U11.11 (GND), U11.32 (GND), U11.62 (GND), U11.81 (GND), U11.99 (GND), Y1.2 (G), Y1.4 (G); also elsewhere on the board
unnamed: R35.2, U11.46 (PD3/TXD1/INT3)

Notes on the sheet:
Decoupling Capacitors
RESET
CLK
ICSP Programming Header

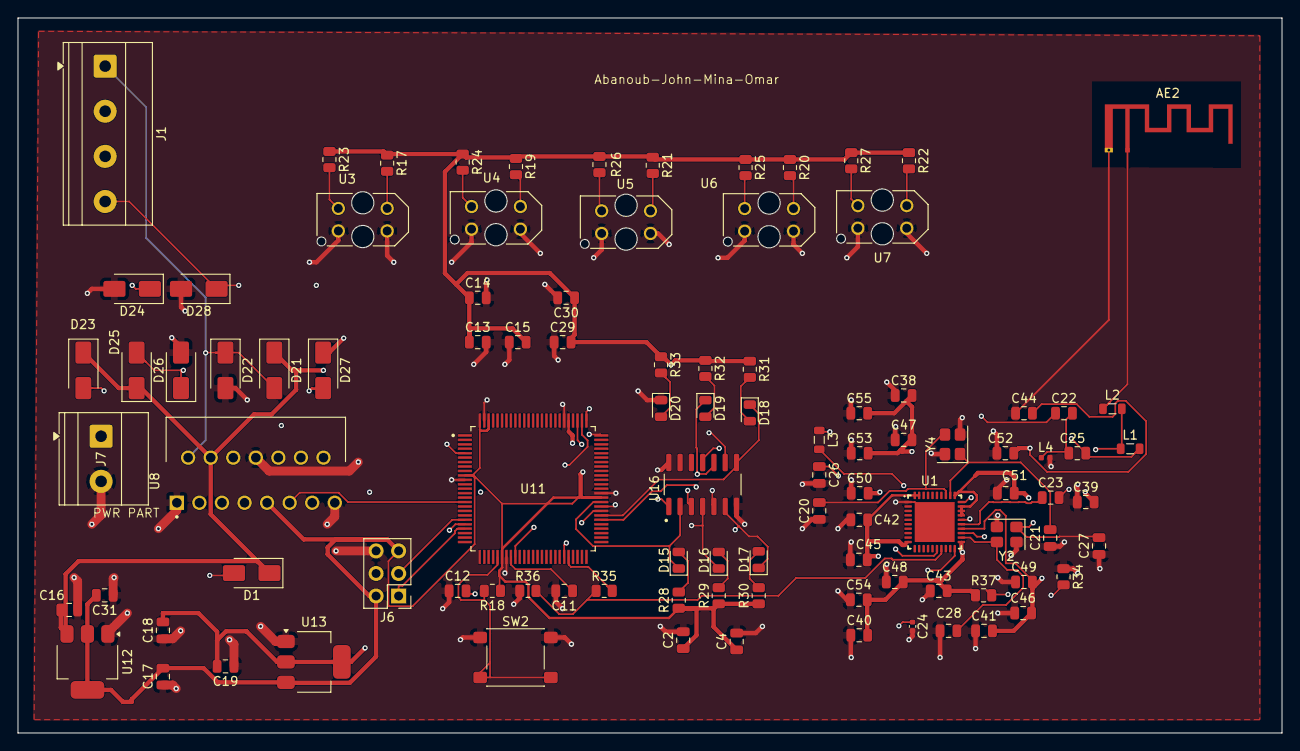
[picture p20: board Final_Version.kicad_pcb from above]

Board: 4 copper layers, 142.3 x 80.5 mm, 99 parts (0 on the bottom side), 58 nets.

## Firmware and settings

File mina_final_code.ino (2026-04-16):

#include <Arduino.h>
#include <EEPROM.h>
#include <ctype.h>

// ===================== BLUETOOTH =====================
// Arduino Mega: Serial1 -> RX1=19, TX1=18
// Typical HC-05 default baud = 9600
HardwareSerial &BT = Serial1;
const unsigned long USB_BAUD = 115200;
const unsigned long BT_BAUD  = 9600;

// ===================== PINS =====================
const uint8_t L_IN1 = 22;
const uint8_t L_IN2 = 23;
const uint8_t R_IN3 = 24;
const uint8_t R_IN4 = 25;
const uint8_t EN_LEFT  = 5;
const uint8_t EN_RIGHT = 6;

const uint8_t SENS_PINS[5] = {30, 31, 32, 33, 34};   // left -> right
const uint8_t LED_PIN = 13;

const uint8_t SENSOR_LINE_LOW = LOW;   // active-low sensors

// ===================== SPEEDS =====================
const int BASE_SPEED            = 67;
const int TURN_SPEED            = 110;   // normal left/right turn speed
const int UTURN_SPEED           = 117;   // separate speed only for U-turn
const int SEARCH_SPEED          = 72;
const int PROBE_SPEED           = 52;
const int DEAD_END_PROBE_SPEED  = 58;
const int START_SPEED           = 58;
const int ALIGN_SPEED           = 70;
const int POST_TURN_SPEED       = 65;

// ===================== TIMING =====================
const unsigned long START_BOX_CONFIRM_MS  = 300;
const unsigned long START_EXIT_TIMEOUT_MS = 1200;

const unsigned long NODE_LOCKOUT_MS       = 105;
const unsigned long END_CONFIRM_MS        = 260;
const unsigned long PROBE_ENTRY_MS        = 55;
const unsigned long PROBE_STRAIGHT_MS     = 90;

const unsigned long DEAD_END_PROBE_MS     = 150;

const unsigned long LOST_LINE_TIMEOUT_MS  = 180;

// Suppress training dead-end recovery briefly after any junction/forced probe (line reacquire gap).
const unsigned long DEAD_END_GRACE_AFTER_NODE_MS = 480;
const unsigned long TURN_TIMEOUT_MS       = 1000;
const unsigned long UTURN_TIMEOUT_MS      = 1500;
const unsigned long ALIGN_TIMEOUT_MS      = 3000;
const unsigned long ALIGN_STABLE_MS       = 40;

const unsigned long POST_TURN_FORWARD_MS  = 60;
const unsigned long POST_TURN_SETTLE_MS   = 20;

// Training record: burst samples + deferred resolve (motion unchanged — first sample = old single read)
const uint8_t PROBE_BURST_N        = 12;
const uint8_t MAX_EXIT_CANDIDATES  = 32;
const unsigned long RECORD_RESOLVE_MS = 220;

// ===================== STORAGE =====================
const int MAX_NODES = 200;

// raw training decisions (real junction decisions only)
// L = chose left at real intersection
// S = chose straight at real intersection
// R = chose right at real intersection
// B = dead end / U-turn
char rawPath[MAX_NODES + 1];
char optimalPath[MAX_NODES + 1];

// bit0 = left exit exists
// bit1 = straight exit exists
// bit2 = right exit exists
uint8_t exitsRecorded[MAX_NODES];

// time between stored nodes
unsigned int segmentTimeMs[MAX_NODES];

int rawPathLen = 0;
int optimalPathLen = 0;
int solveStepIndex = 0;

// Deferred training junction record (dynamic exit mask resolution)
bool pendingTrainingRecord = false;
unsigned int pendingSegMs = 0;
char pendingTurn = 0;
uint8_t pendingPrimaryMask = 0;
unsigned long pendingRecordStartMs = 0;
bool recordWitnessLeft = false;
bool recordWitnessRight = false;

uint8_t candMask[MAX_EXIT_CANDIDATES];
uint8_t candVotes[MAX_EXIT_CANDIDATES];
uint8_t candCount = 0;

// ===================== EEPROM LAYOUT =====================
const uint32_t EEPROM_MAGIC   = 0x4D415A45UL; // "MAZE"
const uint16_t EEPROM_VERSION = 1;

struct EepromMazeData
{
  uint32_t magic;
  uint16_t version;
  uint16_t rawLen;
  uint16_t optLen;
  char raw[MAX_NODES + 1];
  char opt[MAX_NODES + 1];
  uint16_t checksum;
};

// ===================== STATE =====================
enum RobotState
{
  WAIT_COMMAND,
  ARM_TRAINING,
  TRAINING,
  READY_TO_SOLVE,
  ARM_SOLVING,
  SOLVING
};

RobotState state = WAIT_COMMAND;

struct SensorState
{
  uint8_t v[5];
  uint8_t onCount;
  bool allBlack;
  bool noLine;
};

SensorState sensors;

unsigned long segmentStartMs    = 0;
unsigned long lastNodeHandledMs = 0;
unsigned long lastLineSeenMs    = 0;
unsigned long startBoxSeenMs    = 0;

int lastSteer = 0;   // -1 left, 0 center, +1 right

// ===================== COMMAND BUFFERS =====================
const uint8_t CMD_BUF_SIZE = 32;
char btCmdBuf[CMD_BUF_SIZE];
char usbCmdBuf[CMD_BUF_SIZE];
uint8_t btCmdIdx = 0;
uint8_t usbCmdIdx = 0;

// ===================== STAGE TEXT =====================
char currentStage[40] = "IDLE";

// ===================== HELPERS =====================
void logLine(const String &msg)
{
  Serial.println(msg);
  BT.println(msg);
}

void setStage(const char *stageText)
{
  if (strcmp(currentStage, stageText) != 0) {
    strncpy(currentStage, stageText, sizeof(currentStage) - 1);
    currentStage[sizeof(currentStage) - 1] = '\0';
    logLine(String("STAGE=") + currentStage);
  }
}

const char* stateName(RobotState s)
{
  switch (s) {
    case WAIT_COMMAND:   return "WAIT_COMMAND";
    case ARM_TRAINING:   return "ARM_TRAINING";
    case TRAINING:       return "TRAINING";
    case READY_TO_SOLVE: return "READY_TO_SOLVE";
    case ARM_SOLVING:    return "ARM_SOLVING";
    case SOLVING:        return "SOLVING";
    default:             return "UNKNOWN";
  }
}

String exitsMaskToString(uint8_t exitsMask)
{
  String s = "";
  if (exitsMask & 0x01) s += 'L';
  if (exitsMask & 0x02) s += 'S';
  if (exitsMask & 0x04) s += 'R';
  if (exitsMask == 0)   s = "DEAD";
  return s;
}

bool validTurnChar(char c)
{
  return (c == 'L' || c == 'S' || c == 'R' || c == 'B');
}

void clearRamPaths()
{
  rawPathLen = 0;
  optimalPathLen = 0;
  solveStepIndex = 0;

  rawPath[0] = '\0';
  optimalPath[0] = '\0';

  memset(exitsRecorded, 0, sizeof(exitsRecorded));
  memset(segmentTimeMs, 0, sizeof(segmentTimeMs));

  segmentStartMs = millis();

  pendingTrainingRecord = false;
  candCount = 0;
  pendingSegMs = 0;
  pendingTurn = 0;
  pendingPrimaryMask = 0;
  recordWitnessLeft = false;
  recordWitnessRight = false;
}

char selectTurn(bool foundLeft, bool foundStraight, bool foundRight);

char turnFromMaskLHR(uint8_t mask)
{
  bool L = (mask & 0x01) != 0;
  bool S = (mask & 0x02) != 0;
  bool R = (mask & 0x04) != 0;
  return selectTurn(L, S, R);
}

void addExitCandidateVote(uint8_t mask)
{
  for (uint8_t i = 0; i < candCount; i++) {
    if (candMask[i] == mask) {
      if (candVotes[i] < 255) {
        candVotes[i]++;
      }
      return;
    }
  }
  if (candCount >= MAX_EXIT_CANDIDATES) {
    return;
  }
  candMask[candCount] = mask;
  candVotes[candCount] = 1;
  candCount++;
}

void buildExitCandidatesFromBursts(const bool *burstL,
                                   const bool *burstR,
                                   const bool *burstS,
                                   uint8_t n)
{
  candCount = 0;
  for (uint8_t ki = 0; ki < n; ki++) {
    for (uint8_t mj = 0; mj < n; mj++) {
      uint8_t m = 0;
      if (burstL[ki]) {
        m |= 0x01;
      }
      if (burstS[mj]) {
        m |= 0x02;
      }
      if (burstR[ki]) {
        m |= 0x04;
      }
      addExitCandidateVote(m);
    }
  }
}

void startPendingTrainingRecord(uint8_t primaryMask, char turn, unsigned int segMs)
{
  pendingTrainingRecord = true;
  pendingPrimaryMask = primaryMask;
  pendingTurn = turn;
  pendingSegMs = segMs;
  recordWitnessLeft = false;
  recordWitnessRight = false;
  pendingRecordStartMs = millis();
}

void trainingRecordAccumulateWitness()
{
  if (sensors.v[0] || sensors.v[1]) {
    recordWitnessLeft = true;
  }
  if (sensors.v[3] || sensors.v[4]) {
    recordWitnessRight = true;
  }
}

void finalizePendingTrainingRecord(bool force)
{
  if (!pendingTrainingRecord) {
    return;
  }
  if (!force && (millis() - pendingRecordStartMs < RECORD_RESOLVE_MS)) {
    return;
  }

  uint8_t bestMask = pendingPrimaryMask;
  int bestScore = -1;
  uint8_t bestVotes = 0;

  for (uint8_t i = 0; i < candCount; i++) {
    uint8_t m = candMask[i];
    if (turnFromMaskLHR(m) != pendingTurn) {
      continue;
    }

    int score = (int)candVotes[i] * 3;
    bool L = (m & 0x01) != 0;
    bool S = (m & 0x02) != 0;
    bool R = (m & 0x04) != 0;
    if (L && recordWitnessLeft) {
      score += 2;
    }
    if (R && recordWitnessRight) {
      score += 2;
    }
    if (S && (recordWitnessLeft || recordWitnessRight)) {
      score += 1;
    }

    if (score > bestScore ||
        (score == bestScore && candVotes[i] > bestVotes)) {
      bestScore = score;
      bestVotes = candVotes[i];
      bestMask = m;
    }
  }

  String msg = String("RECORD_RESOLVED mask=") +
               exitsMaskToString(bestMask) +
               " turn=" + String(pendingTurn) +
               " candN=" + String(candCount) +
               " primary=" + exitsMaskToString(pendingPrimaryMask);
  logLine(msg);

  recordNode(bestMask, pendingTurn, pendingSegMs);

  pendingTrainingRecord = false;
  candCount = 0;
}

void reportStatus()
{
  logLine(String("STATE=") + stateName(state));
  logLine(String("STAGE=") + currentStage);
  logLine(String("RAW_LEN=") + rawPathLen);
  logLine(String("OPT_LEN=") + optimalPathLen);
  logLine(String("SOLVE_INDEX=") + solveStepIndex);

  if (rawPathLen > 0) {
    logLine(String("RAW_PATH=") + rawPath);
  }
  if (optimalPathLen > 0) {
    logLine(String("OPTIMAL_PATH=") + optimalPath);
  }
}

void printTrainingSummary()
{
  logLine("=== TRAINING SUMMARY ===");
  logLine(String("RAW_PATH=") + rawPath);
  logLine(String("OPTIMAL_PATH=") + optimalPath);

  for (int i = 0; i < rawPathLen; i++) {
    String line = String(i) +
                  ": exits=" + exitsMaskToString(exitsRecorded[i]) +
                  ", turn=" + String(rawPath[i]) +
                  ", segMs=" + String(segmentTimeMs[i]);
    logLine(line);
  }
}

// ===================== EEPROM =====================
uint16_t calcEepromChecksum(const EepromMazeData &d)
{
  uint32_t sum = 0;
  sum += (uint16_t)(d.magic & 0xFFFF);
  sum += (uint16_t)((d.magic >> 16) & 0xFFFF);
  sum += d.version;
  sum += d.rawLen;
  sum += d.optLen;

  for (int i = 0; i < MAX_NODES + 1; i++) {
    sum += (uint8_t)d.raw[i];
    sum += (uint8_t)d.opt[i];
  }

  return (uint16_t)(sum & 0xFFFF);
}

bool savePathsToEEPROM()
{
  EepromMazeData data;
  memset(&data, 0, sizeof(data));

  data.magic   = EEPROM_MAGIC;
  data.version = EEPROM_VERSION;
  data.rawLen  = rawPathLen;
  data.optLen  = optimalPathLen;

  strncpy(data.raw, rawPath, MAX_NODES);
  strncpy(data.opt, optimalPath, MAX_NODES);

  data.raw[MAX_NODES] = '\0';
  data.opt[MAX_NODES] = '\0';
  data.checksum = calcEepromChecksum(data);

  EEPROM.put(0, data);

  EepromMazeData verify;
  EEPROM.get(0, verify);

  return (verify.magic == EEPROM_MAGIC &&
          verify.version == EEPROM_VERSION &&
          verify.checksum == calcEepromChecksum(verify));
}

bool loadPathsFromEEPROM()
{
  EepromMazeData data;
  EEPROM.get(0, data);

  if (data.magic != EEPROM_MAGIC) return false;
  if (data.version != EEPROM_VERSION) return false;
  if (data.rawLen > MAX_NODES) return false;
  if (data.optLen > MAX_NODES) return false;
  if (data.checksum != calcEepromChecksum(data)) return false;

  for (int i = 0; i < data.rawLen; i++) {
    if (!validTurnChar(data.raw[i])) return false;
  }
  for (int i = 0; i < data.optLen; i++) {
    if (!validTurnChar(data.opt[i])) return false;
  }

  clearRamPaths();

  rawPathLen = data.rawLen;
  optimalPathLen = data.optLen;

  memcpy(rawPath, data.raw, MAX_NODES + 1);
  memcpy(optimalPath, data.opt, MAX_NODES + 1);

  rawPath[rawPathLen] = '\0';
  optimalPath[optimalPathLen] = '\0';

  solveStepIndex = 0;
  return true;
}

void clearEEPROMPaths()
{
  EepromMazeData data;
  memset(&data, 0, sizeof(data));
  EEPROM.put(0, data);
}

// ===================== MOTOR HELPERS =====================
void setLeft(int pwm)
{
  if (pwm > 0) {
    digitalWrite(L_IN1, HIGH);
    digitalWrite(L_IN2, LOW);
    analogWrite(EN_LEFT, pwm);
  } else if (pwm < 0) {
    digitalWrite(L_IN1, LOW);
    digitalWrite(L_IN2, HIGH);
    analogWrite(EN_LEFT, -pwm);
  } else {
    digitalWrite(L_IN1, LOW);
    digitalWrite(L_IN2, LOW);
    analogWrite(EN_LEFT, 0);
  }
}

void setRight(int pwm)
{
  if (pwm > 0) {
    digitalWrite(R_IN3, LOW);
    digitalWrite(R_IN4, HIGH);
    analogWrite(EN_RIGHT, pwm);
  } else if (pwm < 0) {
    digitalWrite(R_IN3, HIGH);
    digitalWrite(R_IN4, LOW);
    analogWrite(EN_RIGHT, -pwm);
  } else {
    digitalWrite(R_IN3, LOW);
    digitalWrite(R_IN4, LOW);
    analogWrite(EN_RIGHT, 0);
  }
}

void drive(int leftPwm, int rightPwm)
{
  setLeft(leftPwm);
  setRight(rightPwm);
}

void stopMotors()          { drive(0, 0); }
void driveForward(int pwm) { drive(pwm, pwm); }
void spinLeft(int pwm)     { drive(-pwm, pwm); }
void spinRight(int pwm)    { drive(pwm, -pwm); }

// ===================== SENSOR HELPERS =====================
uint8_t sensorOnLine(uint8_t pin)
{
  return (digitalRead(pin) == SENSOR_LINE_LOW) ? 1 : 0;
}

void readSensors()
{
  sensors.onCount = 0;
  for (int i = 0; i < 5; i++) {
    sensors.v[i] = sensorOnLine(SENS_PINS[i]);
    sensors.onCount += sensors.v[i];
  }

  sensors.allBlack = (sensors.onCount == 5);
  sensors.noLine   = (sensors.onCount == 0);
}

bool isPerfectCenterPattern()
{
  return sensors.v[2] &&
         !sensors.v[0] &&
         !sensors.v[1] &&
         !sensors.v[3] &&
         !sensors.v[4];
}

// candidate node = maybe intersection / cross / finish region
bool nodeCandidateNow()
{
  if (sensors.allBlack) return true;

  bool outerWithBody = (sensors.v[0] || sensors.v[4]) &&
                       (sensors.v[1] || sensors.v[2] || sensors.v[3]);

  bool wideCenter = sensors.v[1] && sensors.v[2] && sensors.v[3];

  return outerWithBody || wideCenter;
}

// ===================== PATH OPTIMIZATION =====================
char selectTurn(bool foundLeft, bool foundStraight, bool foundRight)
{
  if (foundLeft)     return 'L';
  if (foundStraight) return 'S';
  if (foundRight)    return 'R';
  return 'B';
}

int turnAngle(char t)
{
  switch (t) {
    case 'L': return 270;
    case 'S': return 0;
    case 'R': return 90;
    case 'B': return 180;
    default:  return 0;
  }
}

char angleToTurn(int angle)
{
  angle %= 360;
  if (angle < 0) angle += 360;

  switch (angle) {
    case 0:   return 'S';
    case 90:  return 'R';
    case 180: return 'B';
    case 270: return 'L';
    default:  return 'S';
  }
}

void buildOptimalPath()
{
  optimalPathLen = 0;
  optimalPath[0] = '\0';

  for (int i = 0; i < rawPathLen; i++) {
    if (optimalPathLen >= MAX_NODES) break;

    optimalPath[optimalPathLen++] = rawPath[i];
    optimalPath[optimalPathLen] = '\0';

    while (optimalPathLen >= 3 && optimalPath[optimalPathLen - 2] == 'B') {
      int totalAngle =
        turnAngle(optimalPath[optimalPathLen - 3]) +
        turnAngle(optimalPath[optimalPathLen - 2]) +
        turnAngle(optimalPath[optimalPathLen - 1]);

      char reduced = angleToTurn(totalAngle);

      optimalPathLen -= 3;
      optimalPath[optimalPathLen++] = reduced;
      optimalPath[optimalPathLen] = '\0';
    }
  }
}

void recordNode(uint8_t exitsMask, char turnTaken, unsigned int segMs)
{
  if (rawPathLen >= MAX_NODES) return;

  rawPath[rawPathLen] = turnTaken;
  exitsRecorded[rawPathLen] = exitsMask;
  segmentTimeMs[rawPathLen] = segMs;
  rawPathLen++;
  rawPath[rawPathLen] = '\0';

  segmentStartMs = millis();

  String msg = String("NODE ") +
               String(rawPathLen - 1) +
               " exits=" + exitsMaskToString(exitsMask) +
               " turn=" + String(turnTaken) +
               " segMs=" + String(segMs);

  logLine(msg);
}

bool turnExists(char requested, bool foundLeft, bool foundStraight, bool foundRight)
{
  switch (requested) {
    case 'L': return foundLeft;
    case 'S': return foundStraight;
    case 'R': return foundRight;
    case 'B': return true;
    default:  return false;
  }
}

// ===================== ALIGNMENT =====================
void alignToCenterStrict(unsigned long timeoutMs = ALIGN_TIMEOUT_MS)
{
  unsigned long t0 = millis();
  unsigned long stableStart = 0;

  while (millis() - t0 < timeoutMs) {
    readSensors();

    if (isPerfectCenterPattern()) {
      if (stableStart == 0) stableStart = millis();
      stopMotors();

      if (millis() - stableStart >= ALIGN_STABLE_MS) {
        return;
      }
      continue;
    }

    stableStart = 0;

    if ((sensors.v[0] || sensors.v[1]) && !sensors.v[3] && !sensors.v[4]) {
      lastSteer = -1;
      spinLeft(ALIGN_SPEED);
    }
    else if ((sensors.v[3] || sensors.v[4]) && !sensors.v[0] && !sensors.v[1]) {
      lastSteer = 1;
      spinRight(ALIGN_SPEED);
    }
    else if (sensors.v[2] && sensors.v[1] && !sensors.v[3]) {
      lastSteer = -1;
      spinLeft(ALIGN_SPEED);
    }
    else if (sensors.v[2] && sensors.v[3] && !sensors.v[1]) {
      lastSteer = 1;
      spinRight(ALIGN_SPEED);
    }
    else if (sensors.noLine) {
      if (lastSteer <= 0) spinLeft(ALIGN_SPEED);
      else                spinRight(ALIGN_SPEED);
    }
    else {
      if (lastSteer <= 0) spinLeft(ALIGN_SPEED);
      else                spinRight(ALIGN_SPEED);
    }
  }

  stopMotors();
}

void alignThenMove()
{
  alignToCenterStrict();

  stopMotors();
  delay(POST_TURN_SETTLE_MS);

  readSensors();

  if (!isPerfectCenterPattern()) {
    return;
  }

  unsigned long t0 = millis();
  while (millis() - t0 < POST_TURN_FORWARD_MS) {
    readSensors();

    if (isPerfectCenterPattern() ||
        (sensors.v[2] && !sensors.v[0] && !sensors.v[4])) {
      driveForward(POST_TURN_SPEED);
    } else {
      break;
    }
  }

  stopMotors();
}

// ===================== TURNING =====================
void doTurn(char dir)
{
  unsigned long t0 = millis();
  bool centerWentOff = false;

  if (dir == 'S') {
    alignThenMove();
    return;
  }

  if (dir == 'L') {
    lastSteer = -1;

    while (millis() - t0 < TURN_TIMEOUT_MS) {
      readSensors();
      spinLeft(TURN_SPEED);

      if (!sensors.v[2]) centerWentOff = true;

      if (centerWentOff && sensors.v[2] && !sensors.allBlack) {
        break;
      }
    }

    stopMotors();
    alignThenMove();
    return;
  }

  if (dir == 'R') {
    lastSteer = 1;

    while (millis() - t0 < TURN_TIMEOUT_MS) {
      readSensors();
      spinRight(TURN_SPEED);

      if (!sensors.v[2]) centerWentOff = true;

      if (centerWentOff && sensors.v[2] && !sensors.allBlack) {
        break;
      }
    }

    stopMotors();
    alignThenMove();
    return;
  }

  if (dir == 'B') {
    lastSteer = 1;

    while (millis() - t0 < UTURN_TIMEOUT_MS) {
      readSensors();
      spinRight(UTURN_SPEED);

      if (millis() - t0 > 180 && sensors.v[2] && !sensors.allBlack) {
        break;
      }
    }

    stopMotors();
    alignThenMove();
    return;
  }
}

// ===================== DEAD-END RECOVERY =====================
bool persistentNoLine()
{
  return sensors.noLine &&
         (millis() - lastLineSeenMs >= LOST_LINE_TIMEOUT_MS);
}

void deadEndProbeForward()
{
  unsigned long t0 = millis();

  while (millis() - t0 < DEAD_END_PROBE_MS) {
    driveForward(DEAD_END_PROBE_SPEED);
    readSensors();
  }

  stopMotors();
}

void handleTrainingDeadEndRecovery()
{
  stopMotors();
  setStage("TRAINING_DEAD_END");

  unsigned int segMs = (unsigned int)(millis() - segmentStartMs);

  logLine("DEAD_END_DETECTED");
  logLine(String("DEAD_END_RECOVERY_NO_PATH segMs=") + String(segMs));
  recordNode(0, 'B', segMs);

  deadEndProbeForward();
  doTurn('B');

  segmentStartMs = millis();

  lastLineSeenMs = millis();
  lastNodeHandledMs = millis();
  setStage("TRAINING_FOLLOW_LINE");
}

void handleSolvingDeadEndRecovery()
{
  stopMotors();
  setStage("SOLVING_DEAD_END");

  logLine("UNEXPECTED_DEAD_END_DETECTED");

  deadEndProbeForward();
  doTurn('B');

  lastLineSeenMs = millis();
  lastNodeHandledMs = millis();
  setStage("SOLVING_FOLLOW_LINE");
}

// ===================== NO-PID LINE FOLLOW =====================
void followLineNoPID()
{
  readSensors();

  if (!sensors.noLine) {
    lastLineSeenMs = millis();
  }

  if (isPerfectCenterPattern()) {
    lastSteer = 0;
    driveForward(BASE_SPEED);
    return;
  }

  if (sensors.v[2] && sensors.v[1] && !sensors.v[3]) {
    lastSteer = -1;
    spinLeft(ALIGN_SPEED);
    return;
  }

  if (sensors.v[2] && sensors.v[3] && !sensors.v[1]) {
    lastSteer = 1;
    spinRight(ALIGN_SPEED);
    return;
  }

  if (sensors.v[0] || (sensors.v[1] && !sensors.v[2])) {
    lastSteer = -1;
    spinLeft(TURN_SPEED);
    return;
  }

  if (sensors.v[4] || (sensors.v[3] && !sensors.v[2])) {
    lastSteer = 1;
    spinRight(TURN_SPEED);
    return;
  }

  if (sensors.noLine) {
    if (millis() - lastLineSeenMs < LOST_LINE_TIMEOUT_MS) {
      stopMotors();
    } else {
      if (lastSteer <= 0) spinLeft(SEARCH_SPEED);
      else                spinRight(SEARCH_SPEED);
    }
    return;
  }

  if (sensors.v[2]) {
    stopMotors();
    return;
  }

  if (lastSteer <= 0) spinLeft(SEARCH_SPEED);
  else                spinRight(SEARCH_SPEED);
}

// ===================== FINISH DETECTION =====================
bool confirmEndBox()
{
  unsigned long t0 = millis();

  while (millis() - t0 < END_CONFIRM_MS) {
    driveForward(PROBE_SPEED);
    readSensors();
    if (!sensors.allBlack) return false;
  }

  stopMotors();
  return true;
}
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
void loop()
{
  pollCommands();
  updateLedPattern();

  switch (state) {
    case WAIT_COMMAND:
      stopMotors();
      break;

    case ARM_TRAINING:
      handleArmTraining();
      break;

    case TRAINING:
      handleTraining();
      break;

    case READY_TO_SOLVE:
      stopMotors();
      break;

    case ARM_SOLVING:
      handleArmSolving();
      break;

    case SOLVING:
      handleSolving();
      break;
  }
}

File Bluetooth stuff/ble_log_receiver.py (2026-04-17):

"""
Stream telemetry from the robot over Bluetooth Classic SPP (ZS-040 / HC-05 on macOS).

Same serial device as maze_dashboard — pair the module in System Settings → Bluetooth,
then:

  export MAZE_BT_SERIAL=/dev/cu.HC-05-DevB
  export MAZE_BT_BAUD=9600
  python ble_log_receiver.py

Reuse last successful dashboard port:

  export MAZE_BT_SERIAL=last

(Run the dashboard once with a real path so maze_dashboard/bt_serial_last.json exists.)
"""
from __future__ import annotations

import json
import os
import sys
from pathlib import Path

SCRIPT_DIR = Path(__file__).resolve().parent
BT_SERIAL_LAST_PATH = SCRIPT_DIR / "maze_dashboard" / "bt_serial_last.json"


def emit(event_type: str, **payload: object) -> None:
    event: dict[str, object] = {"type": event_type, **payload}
    print(json.dumps(event), flush=True)


def emit_status(state: str, message: str | None = None, error: str | None = None) -> None:
    payload: dict[str, object] = {"state": state, "message": message or status_label(state)}
    if error:
        payload["error"] = error
    emit("status", **payload)


def status_label(state: str) -> str:
    if state == "connected":
        return "Serial connected"
    if state == "offline":
        return "Serial not configured or unavailable"
    return state


def _load_last_port() -> str | None:
    if not BT_SERIAL_LAST_PATH.is_file():
        return None
    try:
        data = json.loads(BT_SERIAL_LAST_PATH.read_text(encoding="utf-8"))
        p = str(data.get("port", "")).strip()
        if p.startswith("/dev/"):
            return p
    except (OSError, json.JSONDecodeError, TypeError, ValueError):
        pass
    return None


def resolve_port() -> str | None:
    raw = (os.environ.get("MAZE_BT_SERIAL") or os.environ.get("MAZE_SERIAL_PORT") or "").strip()
    if not raw:
        return None
    if raw.lower() == "last":
        return _load_last_port()
    return raw


def main() -> int:
    try:
        import serial
    except ImportError:
        emit_status(
            "offline",
            message="Install pyserial",
            error='pip install pyserial   (also in maze_dashboard/requirements.txt)',
        )
        return 1

    port = resolve_port()
    if not port:
        emit_status(
            "offline",
            message="Set MAZE_BT_SERIAL for ZS-040 / HC-05",
            error="Example: export MAZE_BT_SERIAL=/dev/cu.HC-05-DevB  (use ls /dev/cu.* after pairing)",
        )
        return 0

    try:
        baud = int(os.environ.get("MAZE_BT_BAUD", "9600") or 9600)
    except ValueError:
        baud = 9600

    if not Path(port).exists():
        emit_status("offline", message=f"Missing {port}", error="Pair the module and check /dev/cu.*")
        return 1

    try:
        ser = serial.Serial(port, baud, timeout=0.3)
    except Exception as e:
        emit_status("offline", message=f"Could not open {port}", error=str(e))
        return 1

    emit_status("connected", message=f"Reading {port} @ {baud} baud")
    try:
        while True:
            raw = ser.readline()
            if not raw:
                continue
            line = raw.decode("utf-8", errors="replace").rstrip("\r\n")
            emit("log", line=line)
    except KeyboardInterrupt:
        pass
    finally:
        try:
            ser.close()
        except Exception:
            pass
    emit_status("offline", message="Stopped")
    return 0


if __name__ == "__main__":
    sys.exit(main())

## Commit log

2026-04-16 Initial commit: ECNG 4504 monorepo (MCU, Python host, docs, diagrams)
    Single repository at project root per course GitHub deliverables: Arduino
    sketches, Bluetooth stuff/maze_dashboard Python app, log-viewer, docs including
    project charter and submission mapping.
    Made-with: Cursor
    [component_list(1).xlsx]
2026-04-16 chore: rename BOM to component_list.xlsx and update references
    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
    [component_list.xlsx]
2026-04-16 docs: rewrite README as project report (process and firmware theory)
    Narrate development workflow, then explain LHR mapping, no-PID line follow,
    junction probes, deferred recording, path folding, solve replay, and BLE host
    role. Keep a compact repository index and run commands.
    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
2026-04-17 Sync firmware, maze dashboard, and host tools; document path preview and SPP
    - Update working_code.ino with latest robot behavior.
    - Extend maze_dashboard (BLE/SPP, path preview polyline fix, tests).
    - Refresh ble_log_receiver, log-viewer serve, and requirements.
    - README: Bluetooth SPP setup, path preview note, unittest hint.
    - gitignore: bt_serial_last, Word lockfiles, tmp compile folders.
    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
    [app.py, ble_discover.py, ble_log_receiver.py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]
2026-04-17 docs: expand team.md (host stack, HM-10/ZS-040, Abanoub PCB & Fusion)
    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
2026-04-17 Add KiCAD Stuff: Embedded Project sources and schematic export
    - Track .kicad_pro, .kicad_sch, .kicad_pcb, .kicad_prl, PCB Schematic.png
    - Add KiCAD Stuff/.gitignore for .history, backups, locks
    - README: table entry and KiCad open instructions
    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
    [Embedded Project.kicad_pcb, Embedded Project.kicad_sch]
2026-04-18 fix(dashboard): draw full training geometry (forced + intersection turns)
    RAW_PATH from the firmware only contains intersection turns, so after
    TRAINING_COMPLETE the SVG map dropped every forced corridor exit. Stop
    clearing training_geo_path when RAW_PATH arrives and draw it as the raw
    polyline so forced and intersection turns both appear on the track view.
    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
    [app.py]
2026-05-15 Add Team 5 Phase 2 PCB submission to the repository.
    Ship KiCad project, Gerbers, BOM, PDFs, and screenshots for the embedded
    design milestone, while ignoring KiCad local history, zip backups, and
    Office lock files so the tree stays clean and safe for GitHub.
    [AMS1117-3.3.step, ATmega2560-16AU.step, Bluetooth.kicad_sch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]
